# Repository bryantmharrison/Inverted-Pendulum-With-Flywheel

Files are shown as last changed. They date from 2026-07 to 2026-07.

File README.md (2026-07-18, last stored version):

# Inverted Pendulum With Flywheel
Single DOF Controls Project for AE 4610 (Dynamics and Controls Lab) for Spring 2026.

In AE 4610, I was tasked with constructing a single degree-of-freedom (DOF) system that could be controlled with a single controller. The purpose of this project was to expose the class to designing and implementing. This was a group projected, where I was partnered with Siddharth Balraj, Anushka Dharmasanam, Jonah Isaza, and Bowen Lewis. We were limited to a certain amount of hardware that the lab could provide (microcontrollers, sensors, and actuators) to us and $50 to spend on commerical materials. The project had four components:
1. System dynamics modeling - physics based modeling, system ID, etc.
2. Simulation
3. Controller design and evaluation
4. Physical hardware implementation

## Project Ideation and Proposal
After some brainstorming, the group decided on an inverted pendulum that spins in one plane (SDOF) that is to be held upright, inspired by the following YouTube video:\
Self balancing with reaction wheels (open source) (https://www.youtube.com/watch?v=wacuNeEO2zE)

The goals of the project were devised as follows:
- Create an active motor control to keep the stand within 3 degrees of its upright position.
- The stand will need to angle left and right, using a motor to rotate it towards the vertical. The stand will stay upright, even as mass is added to one side of the system to change the balance.
- The stand should be able to take impacts and return to an upright position. The force applied to the stand will vary (stand will be pushed by hand).

We intended to begin with a proportional-derivative (PD) controller due to its simplicity, then if needed extend to a proportional-integral-derivative (PID) controller. PID controllers are typically more expensive and complicated than a PD, so we chose a simplified starting point. We chose the following controller specifications for the project:
- Set Point: 0 degrees in vertical/upright position 
- Stability duration: Maintain balance for at least 30 seconds 
- Rise time: 1 second 
- Settling Time: 2 seconds - the device should stabilize and stop major oscillations from a leaning start or small external force 
- Steady state error band: +/- 3 degrees from the upright position 
- Maximum overshoot: Less than 15% - the device should not swing past the vertical point excessively

Using the video above as a loose model, we came up with a list of parts that would be required. We did not need many parts, as B.L. elected to 3D print the pendulum on his own 3D printer. We did need, however, a motor, an arduino computer, an IMU to read the pendulum position, a power supply unit, and stock electric parts like a breadboard and wires.\


All of this information was included in a project proposal that was submitted and approved by the class TAs. This proposal is also attached in the repository.

## System Dynamics Modeling
This section was a collaborative effort between myself and J.I., with a little input from B.L. The following image shows a simplified model of the system used for the math behind the system:\


The assumptions made to simplify the mathematics are as follows:
1. Motion is restricted to a single plane.
2. The system can be modeled as a single degree of freedom system.
3. The inverted pendulum is rigid.
4. The reaction wheel is rigid and spins about a fixed axis on its attachment to the inverted pendulum.
5. "Motor torque" refers to the system input.
6. Balancing occurs around the vertical position, so the small angle approximation can be used.
7. All other forces and considerations (drag, friction, etc.) are ignored.

The full derivation of the equations of motion (EOMs) can be found in the report attached to this repository. The final EOMs in state-space form are as follows:\


**Note:** $x_1$ represents the angle of the arm, $x_2$ represents the angular speed of the arm, $x_3$ represents the speed of the system as a whole, and $u$ represents the system input.

After B.L. printed the hardware, each piece was measured and the parameters were found to be the following values:
- $m=0.23746 \ kg$
- $l=0.153 \ m$
- $J_p=0.004514 \ kgm^2$
- $J_w=4.73315∗10^{−4} \ kgm^2$

Thus, the numerical EOMs are:\


## Simulation
This section was primarily completed by S.B. He developed the following SIMULINK model of the system:\


This model simulates the system's reaction to a disturbance via a pulse of magnitude $-0.1 \ rad$ applied for one second. The model runs this input through the state space model generated in the previous section. The simulation pulls plots of arm angle (theta), wheel angle (omega), and motor torque (tau). Bryson's rule was applied with $\theta_{max}=0.052 \ rad$, $\dot\theta_{max}=0.1 \ rad/s$, $\omega_{max}=2\pi \ rad/s$, and $U_{max}=5$ to generate values for the system parameters K. These were tweaked until K produced desirable results. The final chosen K values were:
$K=[-56.607 \ -11.658 \ -0.159]$.
These gain values yielded the following graphs through the SIMULINK model:\




Investigating these plots in MATLAB yields the results:
- $t_r<1 \ s$, meeting the one second maximum rise time goal.
- $t_s=8 \ s$, well exceeding the two second settling time goal.
- $e_{ss}=0$, well within the three degree goal.
- $4.7^\circ$ overshoot, within the thirteen degree goal.
- $5.7 \ Nm$ torque.

Although the settling time goal was not met, the simulation yielded valuable values of the controller gains K and gave us insight into how the system might behave when applied to real hardware.

## Controller Design and Evaluation
This section was primarily completed by J.I. Using MATLAB and the state-space system above, he generated gains with MATLAB's lqr() function. This produced $K=[-281.3905 \ -58.1871 \ -0.7958]$. Then, he also generated root locus, Bode, and step response plots for the system:\




## Hardware Implementation
The hardware was mostly designed and constructed by B.L. He designed the pendulum/flywheel in SolidWorks, then he 3D printed all pieces. He assembled them.\



The implementation of the controller, however, was a consistent group effort between everyone on the team. After some trial and error, each electrical component was properly connected with the following wiring diagram:\


We devised an Arduino code (originally written by B.L., J.I., and S.B. then tweaked by A.D. and myself). This ran on the system but was far from successful. The gains were tuned experimentally, starting at the K in the previous section. Finally, we arrived at $K=[5.0 \ 0.5 \ 1.0]$. These values of K managed to balance the pendulum in its upright position! J.I. and I took the data from the Arduino IDE and produced the following plots of the system running:\




These plots reveal that the system was not totally successful, however. But, this was as close as we could get it within the deadline. We are still very proud that we got it working, especially because there were several setbacks. At one point, the project was knocked off of its table and the flywheel broke! B.L. reprinted a new flywheel within the next few hours and we all scrambled to repair the system. The Arduino code was extremely finnicky as well and required significant tweaking until it worked. Other important observations that we found:
- The settling time was very high, likely due to the low derivative gain. However, increasing the derivative gain by any significant amount completely broke the software's functionality. This was very confusing, so we had to work around this.
- The steady state error was also high, likely due to an error in the software. The system had to be calibrated each time to find the zero-point, so any amount off of the exact vertical when calibrating could introduce error in the results.
- Overshoot was extremely high. Periodically, the motor would shoot the pendulum off to one side. This behavior was unexpected, but the system would correct itself.
- The system was very top-heavy. The weight of the motor made this project more difficult than it could have been. A smaller, potentially stronger motor would be more desirable.

AE4610 Stabilization Showcase (https://youtube.com/shorts/q4ul9D1i0qU)

## Presentation of Findings
After everything, a poster was produced by the team to be presented at the AE4610 exhibit. This poster is in the repository. I was in the room the entire time and the rest of the group came and went, as other classes had other final presentations as well. This was very successful, and the TAs and professor claimed to really enjoy seeing our project!

## Final Remarks
Overall, this was a very successful project. We were able to construct and control a SDOF system within the time frame given to us. If we had more time, we could have addressed the issues that were listed above. We would switch out our motor and spend more time editing the Arduino code and tuning the system gains to get better results. This project helped solidify the theory behind controls that were lectured in previous classes. We had to develop our skills in system modeling, system simulation, controller design, and the Arduino IDE. This was a difficult project, and one that I am proud of. The group worked very hard throughout the semester to make this project happen, and it paid off in the end!

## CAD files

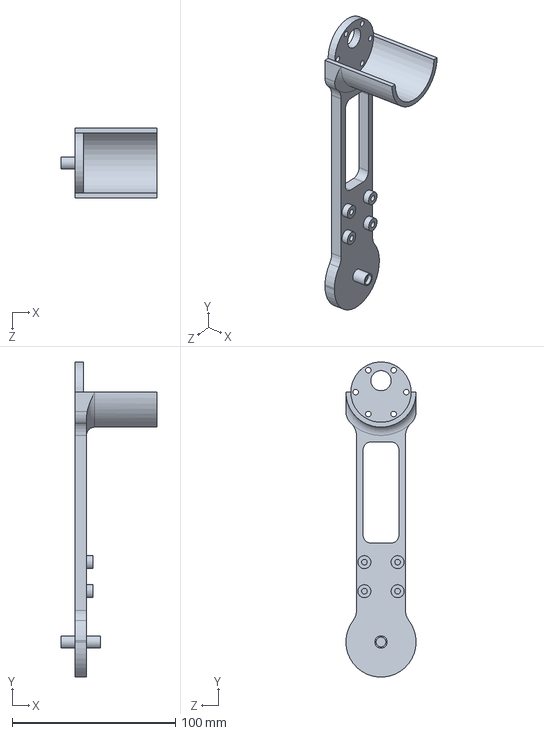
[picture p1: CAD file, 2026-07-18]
Motor and Shaft (160mm).SLDPRT
58.5 x 192.8 x 43.0 mm

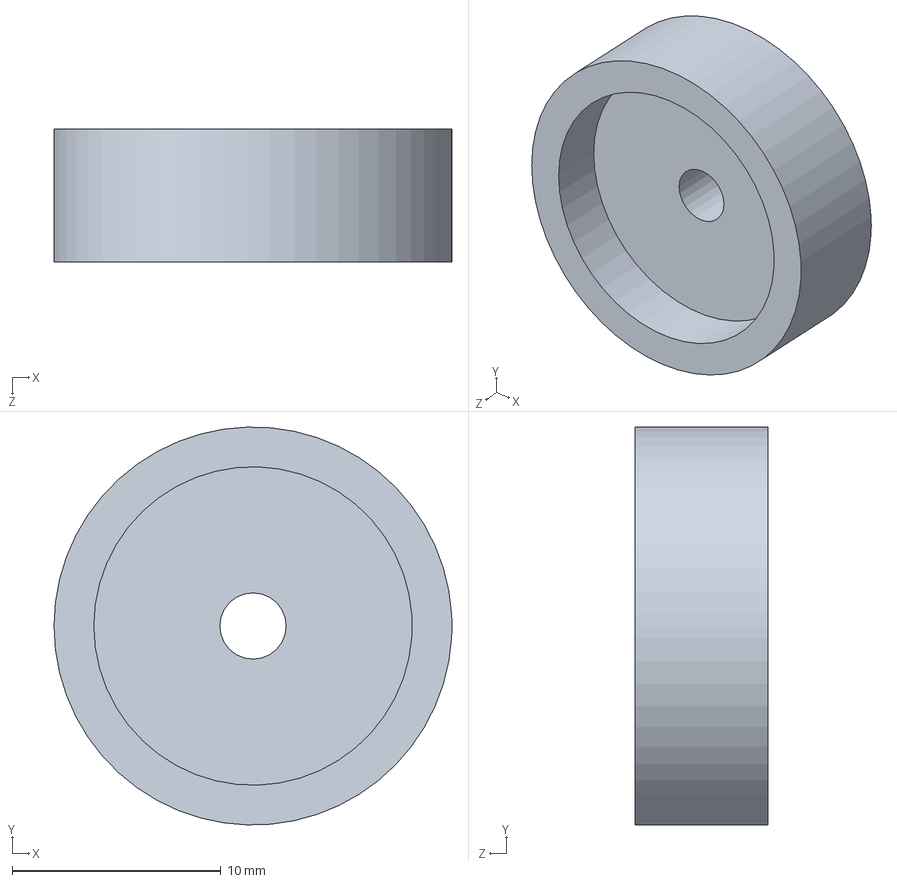
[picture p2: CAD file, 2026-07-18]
MagnetAlignmentPiece.SLDPRT
19.1 x 19.0 x 6.35 mm

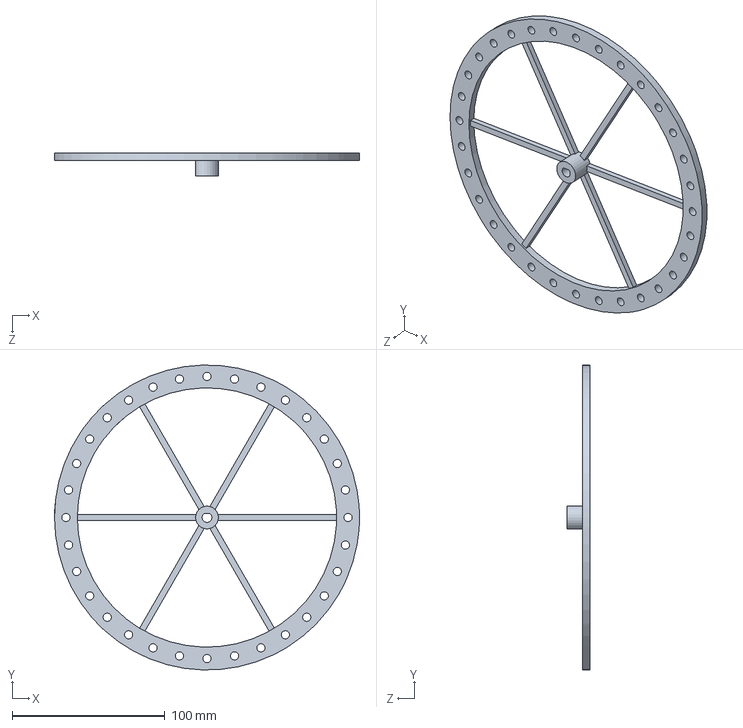
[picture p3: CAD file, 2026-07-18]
Flywheel.SLDPRT
200.0 x 199.9 x 15.0 mm

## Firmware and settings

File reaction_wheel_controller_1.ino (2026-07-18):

/*
 * Reaction Wheel Self-Balancing Stick — PID Controller
 * Target: Arduino Uno R3
 *
 * ARCHITECTURE CHANGE from v3 (full-state feedback) to PID:
 *   - Reference (setpoint) is the calibrated upright position (theta = 0
 *     after thetaOffset is subtracted at startup — same calibration as v3).
 *   - Error = 0 - theta  (positive error = stick leaning negative direction)
 *   - u = Kp*e + Ki*integral(e) + Kd*de/dt
 *   - Integral is clamped (anti-windup) to prevent runaway during large tilts.
 *   - The encoder/omega state is retained in telemetry but is NOT part of
 *     the control law (PID on angle only). You can re-add it as a feed-forward
 *     term later if needed.
 *
 * Everything else is IDENTICAL to v3:
 *   - Calibration logic (3-second average, LED, countdown)
 *   - EEPROM boot counter
 *   - IMU-aware differentiation (dt from IMU timestamps)
 *   - Low-pass filter on theta_dot
 *   - pollImuUntil() non-blocking loop pacing
 *   - All DEBUG flags and telemetry format
 *
 * Hardware pin assignment unchanged from v3.
 * ---------------------------------------------------------------
 */
 
#include <SoftwareSerial.h>
#include <SPI.h>
#include <EEPROM.h>
#include "Adafruit_BNO08x_RVC.h"
 
// ---------------------------------------------------------------
//  PIN DEFINITIONS
// ---------------------------------------------------------------
#define IMU_RX_PIN       4
#define IMU_TX_PIN       5
#define ENCODER_CS_PIN  10
#define MOTOR_ENA_PIN    6
#define MOTOR_IN1_PIN    2
#define MOTOR_IN2_PIN    3
#define CAL_LED_PIN     13
 
// ---------------------------------------------------------------
//  DEBUG FLAGS
// ---------------------------------------------------------------
#define DEBUG_VERBOSE       1
#define DEBUG_RAW_ENCODER   1
#define DEBUG_CONTRIB       1
#define DEBUG_INTERVAL_MS  50
 
// ---------------------------------------------------------------
//  PID GAINS  — tune these
//  Kp: primary restoring force (replaces K1)
//  Ki: eliminates steady-state bias / slow drift
//  Kd: damps oscillation (replaces K2; uses filtered theta_dot)
//
//  Start with Ki = 0 and Kd = 0, tune Kp until it holds, then
//  add Kd to reduce ringing, then a small Ki to remove bias.
// ---------------------------------------------------------------
const float Kp =  5.0f;
const float Ki = 1.0f;   // start at 0, add slowly
const float Kd =  .5; 
 
// Anti-windup: integral is clamped to this band (in radians * seconds)
const float INTEGRAL_LIMIT = 2.5f;
 
const float U_MAX = 5.0f;
 
// ---------------------------------------------------------------
//  CONSTANTS
// ---------------------------------------------------------------
const float COUNTS_PER_REV = 16384.0f;
const float TWO_PI_F       =  6.28318530718f;
const float PI_F           =  3.14159265359f;
const float DEG2RAD        =  0.017453292520f;
const float RAD2DEG        = 57.29577951308f;
 
const unsigned long LOOP_US = 10000UL;   // 100 Hz target
 
// ---------------------------------------------------------------
//  CALIBRATION & FILTER
// ---------------------------------------------------------------
const unsigned long CAL_DURATION_MS = 3000UL;
const unsigned long CAL_MIN_SAMPLES = 20UL;
const float THETA_DOT_ALPHA = 0.3f;
const float THETA_DOT_MAX   = 30.0f;
 
// ---------------------------------------------------------------
//  EEPROM ADDRESS for boot counter
// ---------------------------------------------------------------
#define EEPROM_BOOT_COUNT_ADDR 0   // 2 bytes (uint16_t)
 
// ---------------------------------------------------------------
//  OBJECTS
// ---------------------------------------------------------------
SoftwareSerial       imuSerial(IMU_RX_PIN, IMU_TX_PIN);
Adafruit_BNO08x_RVC rvc;
 
// ---------------------------------------------------------------
//  PLANT STATE  (identical to v3)
// ---------------------------------------------------------------
float theta     = 0.0f;   // stick tilt, rad (calibrated so upright = 0)
float theta_dot = 0.0f;   // filtered angular rate, rad/s
float omega     = 0.0f;   // wheel speed, rad/s (telemetry only)
 
float thetaOffset  = 0.0f;
float thetaPrevImu = 0.0f;
float thetaDotRaw  = 0.0f;
 
float encoderPrev    = 0.0f;
uint16_t encoderRawNow = 0;
 
unsigned long tPrevUs    = 0UL;
unsigned long tPrevImuUs = 0UL;
 
// ---------------------------------------------------------------
//  PID STATE  (new)
// ---------------------------------------------------------------
float pidIntegral   = 0.0f;   // accumulated integral term
float pidError      = 0.0f;   // current error (for telemetry)
float pidP          = 0.0f;   // Kp contribution (for telemetry)
float pidI          = 0.0f;   // Ki contribution (for telemetry)
float pidD          = 0.0f;   // Kd contribution (for telemetry)
 
// ---------------------------------------------------------------
//  DEBUG BOOKKEEPING  (identical to v3)
// ---------------------------------------------------------------
int           lastPwm        = 0;
int           lastDir        = 0;
bool          imuFresh       = false;
unsigned long loopCounter    = 0UL;
unsigned long lastPrintMs    = 0UL;
 
unsigned long imuNewCount    = 0UL;
unsigned long imuHoldCount   = 0UL;
 
unsigned long imuNewWindow   = 0UL;
unsigned long lastHzSampleMs = 0UL;
float         imuHzMeasured  = 0.0f;
 
// ---------------------------------------------------------------
//  FORWARD DECLARATIONS
// ---------------------------------------------------------------
float    readEncoderRad();
float    unwrapDelta(float delta);
float    wrapToPi(float angle);
uint16_t spiTransfer16(uint16_t data);
void     commandMotor(float u);
void     printDebug(float tau, float dt);
void     calibrateZero();
void     pollImuUntil(unsigned long targetUs);
void     printBootCount();
 
// ---------------------------------------------------------------
//  SETUP  (identical to v3)
// ---------------------------------------------------------------
void setup() {
  Serial.begin(115200);
  while (!Serial) { }
 
  Serial.println();
  Serial.println(F("============================================"));
  Serial.println(F("Reaction Wheel Controller — PID"));
  Serial.println(F("============================================"));
 
  printBootCount();
 
  Serial.print(F("Gains: Kp=")); Serial.print(Kp, 4);
  Serial.print(F(" Ki="));       Serial.print(Ki, 4);
  Serial.print(F(" Kd="));       Serial.println(Kd, 4);
  Serial.print(F("Anti-windup limit: +/-")); Serial.println(INTEGRAL_LIMIT, 3);
 
  pinMode(CAL_LED_PIN, OUTPUT);
  digitalWrite(CAL_LED_PIN, LOW);
 
  pinMode(MOTOR_ENA_PIN, OUTPUT);
  pinMode(MOTOR_IN1_PIN, OUTPUT);
  pinMode(MOTOR_IN2_PIN, OUTPUT);
  analogWrite(MOTOR_ENA_PIN, 0);
  digitalWrite(MOTOR_IN1_PIN, LOW);
  digitalWrite(MOTOR_IN2_PIN, LOW);
 
  pinMode(ENCODER_CS_PIN, OUTPUT);
  digitalWrite(ENCODER_CS_PIN, HIGH);
  SPI.begin();
  imuSerial.begin(115200);
 
  if (!rvc.begin(&imuSerial)) {
    Serial.println(F("ERROR: BNO085 not found."));
    while (1) { delay(100); }
  }
  Serial.println(F("BNO085 OK"));
 
  encoderPrev = readEncoderRad();
 
  calibrateZero();   // sets thetaOffset — after this, upright = theta 0
 
  tPrevUs        = micros();
  tPrevImuUs     = tPrevUs;
  lastHzSampleMs = millis();
 
  Serial.println(F("============================================"));
  Serial.println(F("Starting control loop..."));
  Serial.println(F("============================================"));
}
 
// ---------------------------------------------------------------
//  BOOT COUNTER  (identical to v3)
// ---------------------------------------------------------------
void printBootCount() {
  uint16_t n = 0;
  EEPROM.get(EEPROM_BOOT_COUNT_ADDR, n);
  if (n == 0xFFFF) { n = 0; }
  n++;
  EEPROM.put(EEPROM_BOOT_COUNT_ADDR, n);
  Serial.print(F("BOOT #")); Serial.println(n);
  Serial.println(F("(upload a sketch to reset this counter)"));
}
 
// ---------------------------------------------------------------
//  CALIBRATION  (identical to v3)
//  Averages IMU roll over CAL_DURATION_MS while stick is upright.
//  Result stored in thetaOffset so that theta = 0 at the upright.
// ---------------------------------------------------------------
void calibrateZero() {
  Serial.println();
  Serial.println(F(">>> CALIBRATION <<<"));
  Serial.println(F("Hold stick upright. Starting in 3s..."));
 
  for (int i = 3; i > 0; i--) {
    Serial.print(F("  ")); Serial.println(i);
    digitalWrite(CAL_LED_PIN, HIGH);
    unsigned long t0 = millis();
    BNO08x_RVC_Data dump;
    while (millis() - t0 < 500UL) { rvc.read(&dump); }
    digitalWrite(CAL_LED_PIN, LOW);
    t0 = millis();
    while (millis() - t0 < 500UL) { rvc.read(&dump); }
  }
 
  Serial.println(F("Calibrating... (LED solid)"));
  digitalWrite(CAL_LED_PIN, HIGH);
 
  float sumSin = 0.0f;
  float sumCos = 0.0f;
  unsigned long count = 0UL;
  unsigned long tStart = millis();
  BNO08x_RVC_Data h;

  while (millis() - tStart < CAL_DURATION_MS) {
    if (rvc.read(&h)) {
      float r = h.roll * DEG2RAD;
      sumSin += sin(r);
      sumCos += cos(r);
      count++;
    }
  }

  thetaOffset = atan2(sumSin, sumCos);
 
  digitalWrite(CAL_LED_PIN, LOW);
 
  if (count < CAL_MIN_SAMPLES) {
    Serial.print(F("WARNING: only "));
    Serial.print(count);
    Serial.println(F(" samples during cal."));
  }
 
  thetaPrevImu = 0.0f;
 
  // Reset PID state so the integral doesn't start with stale data
  pidIntegral = 0.0f;
 
  Serial.print(F("CAL DONE. samples=")); Serial.print(count);
  Serial.print(F(" rate="));             Serial.print(count / 3.0f, 1);
  Serial.print(F(" Hz  offset="));       Serial.print(thetaOffset, 3);
  Serial.println(F(" deg"));
 
  for (int i = 0; i < 3; i++) {
    digitalWrite(CAL_LED_PIN, HIGH); delay(100);
    digitalWrite(CAL_LED_PIN, LOW);  delay(100);
  }
}
 
// ---------------------------------------------------------------
//  IMU POLLING  (identical to v3)
// ---------------------------------------------------------------
void pollImuUntil(unsigned long targetUs) {
  BNO08x_RVC_Data h;
  while ((long)(micros() - targetUs) < 0) {
    rvc.read(&h);
  }
}
 
// ---------------------------------------------------------------
//  MAIN LOOP
// ---------------------------------------------------------------
void loop() {
  unsigned long tNowUs = micros();
  float dtLoop = (float)(tNowUs - tPrevUs) * 1.0e-6f;
 
  if (dtLoop <= 0.0f || dtLoop > 0.5f) {
    tPrevUs = tNowUs;
    return;
  }
 
  // --- 1. IMU  (identical to v3) ---
  BNO08x_RVC_Data heading;
  imuFresh = false;
  if (rvc.read(&heading)) {
    imuFresh = true;
    imuNewCount++;
    imuNewWindow++;
 
    // NEW (offset subtracted before negation, so zero-crossing is correct):
    float thetaRaw = -(heading.roll * DEG2RAD - thetaOffset);;
    float thetaNew = wrapToPi(thetaRaw);
 
    float dtImu = (float)(tNowUs - tPrevImuUs) * 1.0e-6f;
 
    if (dtImu > 0.0f && dtImu < 0.5f) {
      float dTheta = wrapToPi(thetaNew - thetaPrevImu);
      thetaDotRaw = dTheta / dtImu;
 
      if (thetaDotRaw >  THETA_DOT_MAX) { thetaDotRaw =  THETA_DOT_MAX; }
      if (thetaDotRaw < -THETA_DOT_MAX) { thetaDotRaw = -THETA_DOT_MAX; }
 
      theta_dot = THETA_DOT_ALPHA * thetaDotRaw
                + (1.0f - THETA_DOT_ALPHA) * theta_dot;
    }
 
    theta        = thetaNew;
    thetaPrevImu = thetaNew;
    tPrevImuUs   = tNowUs;
  } else {
    imuHoldCount++;
  }
 
  // --- 2. Encoder  (identical to v3) ---
  float encoderNow = readEncoderRad();
  float delta      = unwrapDelta(encoderNow - encoderPrev);
  omega            = delta / dtLoop;
  encoderPrev      = encoderNow;
  tPrevUs          = tNowUs;
 
  // --- 3. PID control law ---
  //
  //  Reference (setpoint) = 0 rad (calibrated upright position).
  //  Error = reference - measurement = 0 - theta = -theta
  //
  //  Positive error means the stick is leaning in the negative
  //  direction and needs a positive restoring torque.
  //
  //  P term: proportional to error
  //  I term: accumulated error × time (with anti-windup clamp)
  //  D term: rate of change of error = -theta_dot
  //          (we use the filtered theta_dot directly; no separate
  //           error differentiation needed since reference is constant)
 
  pidError = -theta;                             // error = setpoint - theta = 0 - theta
 
  // Integrate only when IMU gave fresh data (avoids integrating stale error)
  if (imuFresh) {
    pidIntegral += pidError * dtLoop;
 
    // Anti-windup: clamp the integral accumulator
    if (pidIntegral >  INTEGRAL_LIMIT) { pidIntegral =  INTEGRAL_LIMIT; }
    if (pidIntegral < -INTEGRAL_LIMIT) { pidIntegral = -INTEGRAL_LIMIT; }
  }
 
  float dError = -theta_dot;   // derivative of error (reference is constant)
 
  pidP = Kp * pidError;
  pidI = Ki * pidIntegral;
  pidD = Kd * dError;
 
  float tau      = pidP + pidI + pidD;
  float tauUnsat = tau;
  tau = constrain(tau, -U_MAX, U_MAX);
 
  // --- 4. Motor ---
  commandMotor(tau);
 
  // --- 5. Update 1-second IMU rate window  (identical to v3) ---
  unsigned long nowMs = millis();
  if (nowMs - lastHzSampleMs >= 1000UL) {
    imuHzMeasured  = (float)imuNewWindow * (1000.0f / (float)(nowMs - lastHzSampleMs));
    imuNewWindow   = 0UL;
    lastHzSampleMs = nowMs;
  }
 
  // --- 6. Telemetry ---
  if (nowMs - lastPrintMs >= (unsigned long)DEBUG_INTERVAL_MS) {
    printDebug(tau, dtLoop);
    if (tauUnsat != tau) {
#if DEBUG_VERBOSE == 1
      Serial.print(F("  [SAT] unsat tau = "));
      Serial.println(tauUnsat, 3);
#endif
    }
    lastPrintMs = nowMs;
  }
 
  loopCounter++;
 
  // --- 7. Pace loop (poll IMU during the wait)  (identical to v3) ---
  unsigned long deadline = tNowUs + LOOP_US;
  pollImuUntil(deadline);
}
 
// ---------------------------------------------------------------
//  DEBUG PRINTER
//  Same format as v3 but shows P/I/D contributions instead of
//  K1*theta / K2*theta_dot / K3*omega.
// ---------------------------------------------------------------
void printDebug(float tau, float dt) {
  float thetaDeg = theta * RAD2DEG;
 
#if DEBUG_VERBOSE == 1
  float totalCycles = (float)(imuNewCount + imuHoldCount);
  float lifetimePct = (totalCycles > 0.0f)
                    ? (100.0f * (float)imuNewCount / totalCycles)
                    : 0.0f;
 
  Serial.print(F("t="));           Serial.print(millis());
  Serial.print(F("ms  loop#="));   Serial.print(loopCounter);
  Serial.print(F("  dt="));        Serial.print(dt * 1000.0f, 2);
  Serial.print(F("ms  imu="));     Serial.print(imuFresh ? F("NEW") : F("hold"));
  Serial.print(F("  rate="));      Serial.print(imuHzMeasured, 0);
  Serial.print(F("Hz life="));     Serial.print(lifetimePct, 0);
  Serial.println(F("%"));
 
  Serial.print(F("  STATE  theta="));    Serial.print(thetaDeg, 2);
  Serial.print(F(" deg  error="));       Serial.print(pidError * RAD2DEG, 2);
  Serial.print(F(" deg  theta_dot="));   Serial.print(theta_dot, 3);
  Serial.print(F(" (raw="));             Serial.print(thetaDotRaw, 3);
  Serial.print(F(")  omega="));          Serial.print(omega, 3);
  Serial.println(F(" rad/s"));
 
#if DEBUG_RAW_ENCODER == 1
  Serial.print(F("  ENC    raw="));  Serial.print(encoderRawNow);
  Serial.print(F("/16384  angle=")); Serial.print(encoderPrev, 4);
  Serial.println(F(" rad"));
#endif
 
#if DEBUG_CONTRIB == 1
  Serial.print(F("  PID    P="));        Serial.print(pidP, 3);
  Serial.print(F("  I="));               Serial.print(pidI, 3);
  Serial.print(F("  D="));               Serial.print(pidD, 3);
  Serial.print(F("  integ="));           Serial.println(pidIntegral, 4);
#endif
 
  Serial.print(F("  CMD    tau="));  Serial.print(tau, 3);
  Serial.print(F("  pwm="));         Serial.print(lastPwm);
  Serial.print(F("/255  dir="));
  if      (lastDir > 0) { Serial.println(F("FWD")); }
  else if (lastDir < 0) { Serial.println(F("REV")); }
  else                  { Serial.println(F("COAST")); }
  Serial.println();
 
#else
  // CSV mode (DEBUG_VERBOSE == 0)
  Serial.print(millis());             Serial.print(',');
  Serial.print(thetaDeg, 2);          Serial.print(',');
  Serial.print(pidError * RAD2DEG, 2); Serial.print(',');
  Serial.print(theta_dot, 3);         Serial.print(',');
  Serial.print(omega, 3);             Serial.print(',');
  Serial.print(pidP, 3);              Serial.print(',');
  Serial.print(pidI, 3);              Serial.print(',');
  Serial.print(pidD, 3);              Serial.print(',');
  Serial.print(pidIntegral, 4);       Serial.print(',');
  Serial.print(tau, 3);               Serial.print(',');
  Serial.print(lastPwm);              Serial.print(',');
  Serial.print(lastDir);              Serial.print(',');
  Serial.print(imuHzMeasured, 1);     Serial.print(',');
  Serial.println(imuFresh ? 1 : 0);
#endif
}
 
// ---------------------------------------------------------------
//  ANGLE HELPERS  (identical to v3)
// ---------------------------------------------------------------
float wrapToPi(float angle) {
  while (angle >  PI_F) { angle -= TWO_PI_F; }
  while (angle < -PI_F) { angle += TWO_PI_F; }
  return angle;
}
 
float unwrapDelta(float delta) {
  if (delta >  TWO_PI_F * 0.5f) { delta -= TWO_PI_F; }
  if (delta < -TWO_PI_F * 0.5f) { delta += TWO_PI_F; }
  return delta;
}
 
// ---------------------------------------------------------------
//  ENCODER + SPI  (identical to v3)
// ---------------------------------------------------------------
float readEncoderRad() {
  spiTransfer16(0xFFFF);
  uint16_t raw    = spiTransfer16(0xC000);
  uint16_t counts = raw & 0x3FFF;
  encoderRawNow   = counts;
  return ((float)counts / COUNTS_PER_REV) * TWO_PI_F;
}
 
uint16_t spiTransfer16(uint16_t data) {
  SPI.beginTransaction(SPISettings(1000000UL, MSBFIRST, SPI_MODE1));
  digitalWrite(ENCODER_CS_PIN, LOW);
  uint8_t hi = SPI.transfer((uint8_t)(data >> 8));
  uint8_t lo = SPI.transfer((uint8_t)(data & 0x00FF));
  digitalWrite(ENCODER_CS_PIN, HIGH);
  SPI.endTransaction();
  return ((uint16_t)hi << 8) | (uint16_t)lo;
}
 
// ---------------------------------------------------------------
//  MOTOR  (identical to v3)
// ---------------------------------------------------------------
void commandMotor(float u) {
  // 1. Determine Direction
  if (u > 0.0f) {
    digitalWrite(MOTOR_IN1_PIN, HIGH);
    digitalWrite(MOTOR_IN2_PIN, LOW);
    lastDir = 1;
  } else if (u < 0.0f) {
    digitalWrite(MOTOR_IN1_PIN, LOW);
    digitalWrite(MOTOR_IN2_PIN, HIGH);
    lastDir = -1;
    u = -u; // Use magnitude for PWM calculation
  } else {
    digitalWrite(MOTOR_IN1_PIN, LOW);
    digitalWrite(MOTOR_IN2_PIN, LOW);
    analogWrite(MOTOR_ENA_PIN, 0);
    lastDir = 0;
    lastPwm = 0;
    return;
  }

  // 2. Map Magnitude to PWM (including deadzone compensation)
  const int PWM_MIN = 25; 
  // NEW: map directly from u to [PWM_MIN, 255] without an intermediate zero-crossing:
  int pwm = (int)(PWM_MIN + (255 - PWM_MIN) * (u / U_MAX));

  pwm = constrain(pwm, 0, 255);
  analogWrite(MOTOR_ENA_PIN, pwm);
  lastPwm = pwm;
}
 
 
